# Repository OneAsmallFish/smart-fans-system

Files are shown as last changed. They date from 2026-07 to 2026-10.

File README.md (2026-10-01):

<div align="center">

# 🌀 Smart Fan Controller

**服务器智能风扇控制系统**

*ESP32-S3 powered server fan management — 8-channel PWM, multi-sensor, MQTT, Web dashboard, Home Assistant*










[🌐 Project Page](https://oneasmallfsh.github.io/smart-fans-system/) · [📖 Deploy Guide](docs/deploy.md) · [🔧 Hardware Guide](docs/hardware-assembly.md) · [📡 MQTT Protocol](docs/protocol.md)

</div>

---

## 目录 / Contents

- [功能特性](#-功能特性)
- [系统架构](#-系统架构)
- [快速开始](#-快速开始)
- [硬件规格](#-硬件规格)
- [软件组件](#-软件组件)
- [Web 控制台](#-web-控制台)
- [Home Assistant 集成](#-home-assistant-集成)
- [项目结构](#-项目结构)
- [开发指南](#-开发指南)
- [许可证](#-许可证)

---

## 🏗️ 系统架构

```
┌──────────────────────────────────── 服务器机柜 ─────────────────────────────────────┐
│                                                                                      │
│  ┌─────────────────────────────┐     USB-CDC      ┌──────────────────────────────┐  │
│  │     ESP32-S3-N16R8 (固件)    │ ◄──────────────► │   Go Agent (Linux 守护进程)   │  │
│  │                             │                  │                              │  │
│  │  8× 25kHz PWM 风扇控制       │      MQTT        │  · nvidia-smi  GPU 监控      │  │
│  │  8× PCNT Tach 转速反馈       │ ◄──────────────► │  · /proc/stat  CPU 利用率    │  │
│  │  BME280  温湿度气压           │                  │  · /proc/meminfo 内存        │  │
│  │  DS18B20 远程温度探头         │                  │  · systemd 服务自启动        │  │
│  │  12V/5V/3.3V 电源监控        │                  └──────────────────────────────┘  │
│  │  WS2812B RGB 状态 LED        │                                                    │
│  │  OTA 固件空中升级             │                                                    │
│  └─────────────────────────────┘                                                    │
│               │ SATA 15Pin (12V + 5V)                                               │
└───────────────┼─────────────────────────────────────────────────────────────────────┘
                │ WiFi  ───  MQTT Broker (Mosquitto)
                │                    │
          ┌─────┴──────┐   ┌─────────┼──────────┐   ┌─────────────────────┐
          │  Web APP   │   │  Home   │          │   │   其他 MQTT 客户端   │
          │ React+Node │   │Assistant│ packages │   │  (Node-RED / 脚本)  │
          └─────┬──────┘   └─────────┴──────────┘   └─────────────────────┘
                │ WebSocket 实时推送
                └── Dashboard · 风扇控制 · 告警配置 · 历史图表 · 设备管理
```

## ✨ 功能特性

| 特性 | 说明 |
|---|---|
| 🌡️ **多传感器温度** | BME280 板载（温湿度气压）+ DS18B20 远程探头 + ESP32 内部温度 + GPU/CPU（Go Agent） |
| 🌀 **8路独立风扇** | 25 kHz PWM 精准调速 + PCNT 转速反馈（RPM），停转检测 |
| 📈 **双模控制曲线** | 固定查表（LUT）线性插值 + PID 自适应，每路独立配置 |
| ⚡ **电源监控** | 12V / 5V / 3.3V 实时采样，欠压/过压告警，断电保护电容 |
| 🔔 **智能告警** | 4类规则（温度/停转/电压/WiFi），三级状态机，2分钟去重，LED+MQTT通知 |
| 🌐 **Web 控制台** | React 仪表盘，实时 WebSocket 推送，风扇曲线编辑器，历史趋势图 |
| 🏠 **Home Assistant** | ha/ 手动 packages 集成（17个传感器 + 8路风扇控制 + 5个告警/在线传感器；Discovery 为规划项） |
| 🔄 **OTA 固件更新** | MQTT / USB-CDC 双触发，3阶段回滚保护（启动/网络/MQTT确认） |
| 🖥️ **Go Linux Agent** | nvidia-smi GPU 监控 + /proc 系统采集，单二进制，systemd 服务 |
| 🔌 **SATA 直取供电** | 服务器 SATA 电源口供电，5V→AMS1117-3.3V LDO，12V 直供风扇 |

---

## 🚀 快速开始

### 前置要求

```bash
# ESP-IDF v5.3+（固件编译）
. $IDF_PATH/export.sh

# Go 1.22+（Agent）
go version  # go version go1.22 linux/amd64

# Node.js 20+（Web 控制台）
node --version  # v20.x.x

# Mosquitto（MQTT Broker）
mosquitto -v  # 2.x.x
```

### 1 — 烧录固件

```bash
cd firmware
idf.py set-target esp32s3
idf.py build
idf.py -p /dev/ttyACM0 flash monitor
# 首次上电后长按配网键(3s)，连接 FanCtrl-XXXXXX 热点配网
```

### 2 — 部署 Go Agent（Linux 服务器）

```bash
cd agent
make build
sudo bash install.sh    # 安装到 /usr/local/bin + systemd 服务
# 编辑配置
sudo nano /etc/smart-fan-agent/config.yaml  # 填入 MQTT broker 地址和串口路径
sudo systemctl start smart-fan-agent
```

### 3 — 启动 Web 控制台

```bash
# 后端
cd web/backend && npm install && npm start   # http://localhost:3001
# 前端（开发模式）
cd web/frontend && npm install && npm run dev  # http://localhost:5173
```

### 4 — Home Assistant 集成（手动 packages）

```bash
# 1. 获取 device_id（订阅 status topic 或看固件启动日志）
mosquitto_sub -t 'fan-controller/+/status' -v
# 2. 复制 YAML 到 HA 并替换占位符（详见 ha/README.md）
cp -r ha/ /config/packages/fan-controller/
sed -i 's/__DEVICE_ID__/esp32-a1b2c3/g' /config/packages/fan-controller/*.yaml
# 3. configuration.yaml 启用 packages 后重启 HA
```

> 固件不实现 MQTT Discovery 自动发现（规划中）；必须替换 `__DEVICE_ID__` 占位符，
> 否则控制实体无法下发命令。

> 完整部署说明见 [docs/deploy.md](docs/deploy.md)

---

## 🔧 硬件规格

| 参数 | 规格 |
|---|---|
| **主控** | ESP32-S3-N16R8（16MB Flash + 8MB Octal PSRAM） |
| **供电** | SATA 15Pin（12V + 5V），板载 AMS1117-3.3 LDO |
| **风扇** | 8路 4Pin 25kHz PWM（Intel 规范），SATA 12V 直供 |
| **传感器** | BME280（I2C, GPIO17/18）+ DS18B20（1-Wire, GPIO16, 最多4个，不支持寄生供电） |
| **电平转换** | 74AHCT125（ESP32 3.3V → 5V PWM 信号），Tach 5V→3.3V 分压 |
| **LED** | WS2812B-2020 RGB（3.3V 供电，GPIO45 RMT，5种状态模式） |
| **按键** | WiFi 配网（GPIO47，长按3s/10s；AP 配网需输入串口日志打印的4位确认码），复位（EN 引脚） |
| **通信** | WiFi 802.11b/g/n + USB-CDC 原生（无需转串口芯片） |
| **保护** | PTC 保险丝 + 肖特基防反接 + TVS ESD + 断电保护电容 |
| **PCB** | 99mm × 99mm，4 层 FR4（L2 完整 GND），嘉立创免费打样档 |

### 🔑 关键硬件设计决策

- **12V ADC 分压**：`100kΩ + 20kΩ`（ADC 输入≤2.0V，防止超出 ESP32-S3 ADC 上限3.1V）
- **WS2812B 3.3V 供电**：3.3V 时 VIH_min=2.31V < ESP32 VOH=3.0V ✅；若5V供电则逻辑电平不足
- **不使用 SATA 3.3V 引脚**：改用 5V→LDO 方案，电流裕量更大且无 PWDIS 兼容性问题

---

## 💻 软件组件

```
smart-fans-system/
├── firmware/                  # ESP32-S3 固件（ESP-IDF v5.3, C语言）
│   ├── components/            # 13个独立驱动组件
│   │   ├── power_monitor/     # ADC1 电源监控（仅ADC1，避开ADC2/WiFi冲突）
│   │   ├── fan_pwm/           # LEDC 25kHz PWM（LEDC_LOW_SPEED_MODE）
│   │   ├── fan_tach/          # PCNT 转速计（RPM = pulses×60÷2）
│   │   ├── bme280/            # I2C BME280（Bosch 补偿算法，int64_t 防溢出）
│   │   ├── ds18b20/           # OneWire DS18B20（CRC8 + ROM 搜索）
│   │   ├── status_led/        # WS2812B RMT（5种模式：正常/警告/错误/配网/OTA）
│   │   ├── wifi_manager/      # WiFi STA+AP + Captive Portal + 指数退避重连
│   │   ├── mqtt_client/       # MQTT（LWT 遗嘱 + 50条 Flash 离线队列）
│   │   ├── usb_console/       # USB-CDC 串口控制台（7命令：help/status/reboot/ota/fan/wifi/mqtt）
│   │   ├── flash_storage/     # NVS配置 + Wear Levelling 循环日志
│   │   ├── fan_curve/         # LUT插值 + PID Anti-windup + 紧急模式(>80°C)
│   │   ├── alert_manager/     # 4类告警规则 + NORMAL/WARNING/CRITICAL状态机
│   │   └── ota_handler/       # esp_https_ota + 3阶段回滚保护
│   └── test/                  # 13个 Unity 测试文件（未接入 idf.py 构建，见下方说明）
│
├── agent/                     # Go Linux Agent
│   ├── internal/monitor/      # GPU（nvidia-smi）+ 系统（/proc）采集器
│   ├── internal/mqtt/         # MQTT 发布/订阅（paho.mqtt.golang）
│   └── internal/usb/          # USB-CDC 串口双向中继
│
├── web/                       # Web 控制台
│   ├── backend/               # Express + MQTT + WebSocket（2秒推送）
│   │   └── src/routes/        # 8+端点 + Zod 参数校验
│   └── frontend/              # React + TypeScript + Vite + Recharts
│       ├── pages/             # Dashboard · Fans · Alerts · History · Devices
│       └── components/        # TemperatureGauge · FanCard · VoltageBar · CurveEditor
│
├── ha/                        # Home Assistant 手动 packages 配置（__DEVICE_ID__ 占位）
├── hardware/                  # 硬件设计文件（嘉立创 EDA 工程 + BOM + Gerber；旧 KiCad 工程归档 legacy/）
├── test/                      # 端到端集成测试 + 冒烟测试脚本
│   └── simulator/             # 无硬件协议模拟器（esp32-sim0001，Web/HA 全链路联调）
└── docs/                      # 部署指南 + 硬件组装指南 + MQTT协议规范
```

---

## 📊 Web 控制台

浏览器访问 `http://server-ip:5173`（开发）或 nginx 反代后访问。

- **Dashboard** — 实时温度仪表（RadialBarChart）、风扇 RPM/占空比图表、电压进度条、告警横幅
- **Fans** — 8路独立调速滑块（AUTO/MANUAL 切换）、LUT 曲线可视化编辑、PID 参数面板
- **Alerts** — 4类告警规则开关+阈值配置、告警历史时间线（最近100条）
- **History** — 温度/转速趋势图（Recharts LineChart）、时间范围选择（1h/6h/24h/7d）、CSV 导出
- **Devices** — 在线状态监控、OTA 固件更新触发、设备重启（二次确认）

---

## 🏠 Home Assistant 集成（手动 packages）

通过 `ha/` 目录的 YAML packages 手动集成（MQTT Discovery 自动发现为规划项，当前不实现）：

| 实体类型 | 数量 | 说明 |
|---|:---:|---|
| 传感器（Sensor） | 17 | BME280×3 + DS18B20×2（按 address 匹配）+ MCU温度 + 电压×3 + 风扇RPM×8 |
| 风扇（Fan） | 8 | 0~100% 调速控制（command_topic 指令） |
| 二进制传感器 | 5 | 温度告警 / 停转告警 / 电压异常 / WiFi告警 / 设备在线（per-type retained 状态 topic） |

安装步骤与 `__DEVICE_ID__` 占位符替换方法见 [ha/README.md](ha/README.md)。
全部实体带 availability 联动（设备 LWT 下线即不可用）。

---

## 🛠️ 开发指南

### ESP-IDF 已知陷阱（来自实战踩坑）

| # | 陷阱 | 正确做法 |
|---|---|---|
| 1 | `esp_timer_get_time()` 用 `uint32_t` 接收 | **必须 `int64_t`**，72分钟后溢出 |
| 2 | SNTP 在 `WIFI_EVENT_STA_CONNECTED` 启动 | 必须在 `IP_EVENT_STA_GOT_IP` 启动 |
| 3 | `esp_mqtt_client_start()` 在WiFi事件处理器中 | 用 FreeRTOS Timer 延迟调用 |
| 4 | `sscanf` 解析 JSON | 始终用 `cJSON` 库 |
| 5 | `vTaskDelay` 在事件处理器内 | 改用 `esp_rom_delay_us()` |
| 6 | LEDC 硬件渐变 + WiFi 并发 | 手动步进（独立任务），不用 `ledc_set_fade_with_time()` |

### 运行单元测试 / 构建

```bash
# 固件（⚠️ firmware/test/ 的 13 个 Unity 测试文件未接入 idf.py 构建——DESCOPE，
# 见 docs/changelog-modules-v1.2.md DOC-06；当前固件验证以 build + 冒烟为准）
cd firmware && idf.py build

# agent（Linux 交叉编译）
cd agent && GOOS=linux go build ./... && go vet ./...

# web（真实构建命令；无 jest 测试套件，README 此前的 `cd web && npm test` 不存在）
cd web/backend  && npm ci && npm run build   # 产出 dist/server.js
cd web/frontend && npm ci && npm run build   # 产出 dist/index.html
```

### 运行冒烟测试

```bash
./test/smoke_test.sh <mqtt_host> <api_host>
# 预期输出: PASS: 25  FAIL: 0（含 TST-04 协议命令用例；其中 8 项为静态断言）
```

### 无硬件联调（协议模拟器）

```bash
cd test/simulator && npm ci
node simulator.js --broker mqtt://<broker_host>:1883
# 模拟设备 esp32-sim0001 上线并周期上报，可在 Web 控制台查看/控制
# 详见 test/simulator/README.md；契约自检: node selftest.js --broker mqtt://<broker>:1883
```

---

## 📄 许可证

[MIT License](LICENSE) — 自由使用、修改和分发。

本项目为个人 DIY 项目，不提供任何形式的商业支持或质量保证。

---

<div align="center">

Made with ❤️ for homelab enthusiasts · [⭐ Star on GitHub](https://github.com/OneAsmallFish/smart-fans-system)

</div>

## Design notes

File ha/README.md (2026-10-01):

# ha/README.md — Home Assistant 集成步骤（手动 packages 方案）

# Smart Fan Controller — Home Assistant 集成指南

## 前提条件

- Home Assistant 2024.1+
- Mosquitto broker 插件已安装并运行
- Smart Fan Controller 固件已烧录并已连接 WiFi

---

## 集成方法：手动 packages（ha/ 目录）

> **说明**：固件当前**不实现** MQTT Discovery 自动发现（规划中）。
> 集成方式为手动 packages —— 将 `ha/` 目录的 YAML 放入 HA 配置。

### 步骤

1. **获取 device_id**（二选一）：
   - 订阅设备状态 topic，等一条 retained 消息：
     ```bash
     mosquitto_sub -t 'fan-controller/+/status' -v   # 输出里的 esp32-XXXXXX 即 device_id
     ```
   - 或查看固件启动日志（USB-CDC 串口）：`Device ID: esp32-XXXXXX`

2. **获取 DS18B20 探头地址**（用于 sensors.yaml 的两个探头实体）：
   ```bash
   mosquitto_sub -t 'fan-controller/<device_id>/sensor/ds18b20' -v
   # payload 中 sensors[].address 形如 "28-a1b2c3d4e5f6"
   ```

3. **替换占位符并部署**（在仓库根执行）：
   ```bash
   mkdir -p /config/packages/fan-controller
   sed -e 's/__DEVICE_ID__/<你的device_id>/g' \
       -e 's/__DS_ADDR_0__/<探头0地址>/g' \
       -e 's/__DS_ADDR_1__/<探头1地址>/g' \
       ha/fans.yaml ha/alerts.yaml ha/sensors.yaml \
       > /dev/null   # 先 dry-run 确认，或直接逐文件输出：
   # cp 到 HA 配置目录：
   cp ha/fans.yaml ha/alerts.yaml ha/sensors.yaml /config/packages/fan-controller/
   # 然后在 HA 宿主机上执行 sed 批量替换：
   sed -i -e 's/__DEVICE_ID__/esp32-a1b2c3/g' \
          -e 's/__DS_ADDR_0__/28-xxxxxxxxxxxx/g' \
          -e 's/__DS_ADDR_1__/28-yyyyyyyyyyyy/g' \
          /config/packages/fan-controller/*.yaml
   ```

4. **在 configuration.yaml 中启用 packages**：
   ```yaml
   homeassistant:
     packages:
       fan_controller: !include_dir_named packages/fan-controller
   ```

5. **重启 Home Assistant**，实体生效：
   - 温度/湿度/气压（BME280）×3 + DS18B20 探头 ×2 + MCU 温度 ×1
   - 12V / 5V / 3.3V 电压监控 ×3
   - 风扇 0-7 转速（RPM）×8
   - 风扇 0-7 转速控制（0-100%）×8
   - 告警二进制传感器 ×4（温度/停转/电压/WiFi）+ 设备在线 ×1

> ⚠️ **必须替换 `__DEVICE_ID__`**：固件按具体 device_id 订阅命令（不做通配订阅），
> 不替换的 HA 配置将无法控制设备。旧的隐性占位 device_id 已废弃。

---

## 告警自动化示例

```yaml
# 温度过高时发送通知
automation:
  - alias: "Fan Controller High Temperature"
    trigger:
      - platform: state
        entity_id: binary_sensor.fan_controller_temperature_alert
        to: "on"
    action:
      - service: notify.mobile_app
        data:
          message: "服务器温度过高！检查风扇控制器。"
```

---

## MQTT Discovery（规划中）

自动发现为规划功能（protocol.md §8）；当前方案为上述手动 packages。

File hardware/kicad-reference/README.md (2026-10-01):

# hardware/kicad-reference — KiCad 参考稿（非权威）

> **定位（决策 D6）**：嘉立创 EDA 工程（`hardware/lceda/`，用户手绘）是**唯一硬件真源**。
> 本目录的 KiCad 工程是由整改 agent 生成的**对比参照稿**——用于和您在嘉立创中绘制的
> 版本对照电路结构、网络命名与引脚分配。**禁止用于配单、打样或作为设计依据。**

## 文件清单

| 文件 | 说明 |
|---|---|
| `smart-fan-controller-v1.2.kicad_sch` | v1.2 完整原理图（KiCad 10，A2 单页，全局标签建网） |
| `smart-fan-controller-v1.2.kicad_pro` | 配套工程文件（KiCad GUI 直接打开用） |
| `smart-fan-controller-v1.2-ref.pdf` | 原理图 PDF 导出（无需 KiCad 即可对照） |
| `nl.net` | KiCad 网表导出（网络连通性证据） |
| `generate_sch.py` | 生成器脚本（可复现：`python generate_sch.py`，需本机 KiCad 10 标准库） |

## 设计依据

与嘉立创版完全一致，均来自 `hardware/docs/remediation-plan-v1.2.md`（v1.2.2）§1~§3：

- 8 路风扇：GPIO5~12 → 74AHCT125 ×2（OE 全接地）→ FAN1~8_PWM_OUT；每路 PWM 线 10kΩ 下拉（H-17）
- 8 路 Tach：GPIO13/14/15/21/38/39/40/41，每路 10k 上拉(+5V)+10k 串联+10k 下拉+1nF（3R+1C）
- ADC：GPIO1(÷6, 100k/20k)、GPIO2(÷5.7, 47k/10k)、GPIO4(÷5.7, 47k/10k)
- 电源：SATA → F1(≥3A)+D1 → +12V；SATA 5V→F2+D2 与 USB VBUS→D3 二极管或 → +5V → AMS1117-3.3
- USB：USB_C_Receptacle + USBLC6-2P6（VCC=**+5V**，H-08）+ CC 5.1k×2
- WS2812B-2020（GPIO45，串 33R）；BME280（SDO→GND=0x76，CSB→3V3）；DS18B20×2 端子（J11/J12）
- J13 屏幕排针（GPIO42/43/44+10k上拉/48 + I2C）；EN/BOOT 按键+上拉+去抖；WiFi 按键 GPIO47
- GPIO3/46 与 USB-C 未用脚（TX/RX/SBU）全部 no_connect；GPIO35/36/37 no_connect（N16R8 不可用）

## ERC 结果（KiCad 10.0.5 实测）

```
0 Errors / 11 Warnings
```

- 10 × `lib_symbol_mismatch`（74AHCT125）：生成器把 `extends 74LS125` 的继承符号展平嵌入，
  与库文件逐字节不同但引脚/电气完全一致——外观性差异，可忽略。
- 1 × `pin_to_pin`（U5/BME280 SDO ↔ GND）：**有意设计**（SDO 接地选 I2C 地址 0x76），非缺陷。

网表抽查（`nl.net`）：FAN1_PWM={U2.5,U3.2,R4.1}、FAN8_TACH={U2.34,R41.2,R42.1,C20.1}、
RESET={U2.3,R1.2,SW1.1,C6.1}、DS18B20_DQ={U2.9,R52.2,J11.2,J12.2} 等均与设计一一对应。

## 与嘉立创版对照时请以本表为准的差异说明

- 本稿为单页 A2、全局标签建网（无导线），元件摆放按功能分区，不代表 PCB 布局意图。
- 位号与 v1.2 规范一致：J1 SATA、J2 USB-C、J3~J10 风扇座、J11/J12 DS18B20、J13 屏幕、
  U3/U4 为两片 74AHCT125、U5 BME280、U6 USBLC6（注意：设计指南中 USBLC6 记作 U5，此稿为 U6）。
- 去耦电容数量为示意（ESP32 画了 4 只，BOM 要求 ≥8 分布 VDD）。
- 本稿无 PCB。布局/叠层请完全以嘉立创版与设计指南 v1.2 §PCB 约束为准。

## 复现方法

```bash
cd hardware/kicad-reference
python generate_sch.py    # 重新生成 .kicad_sch（覆盖）
# 验证（路径需绝对路径 + .kicad_sch 扩展名）：
"D:/Program Files/KiCad/10.0/bin/kicad-cli.exe" sch erc --output erc.rpt \
  "E:/My_Opjects/smart-fans-system/hardware/kicad-reference/smart-fan-controller-v1.2.kicad_sch"
```

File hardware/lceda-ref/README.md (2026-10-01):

# hardware/lceda-ref — 嘉立创 EDA 参考稿（非权威）

> **定位（决策 D6）**：您在嘉立创 EDA 中手绘的工程是**唯一硬件真源**。
> 本目录记录 agent 通过 EasyEDA Pro API 生成的**对比参照稿**及其脚本，
> 用于与您的手绘版对照电路结构与网络命名。**禁止用于配单/打样。**

## 参照稿位置（EasyEDA Pro 本地工程）

- 工程名：**SmartFan-v1.2-ref**（单机版本地工程）
- 路径：`C:\Users\OneAs\Documents\LCEDA-Pro\projects\SmartFan-v1.2-ref`
- 打开方式：嘉立创 EDA 专业版 → 工程树 → main/SmartFan-v1.2-ref → 双击 `1. P1`

## 完成状态

### ✅ 原理图（完整）
- A0 图页，**95 个元件**全部放置并设位号/名称，全部引脚按 v1.2 网络命名
  （`remediation-plan-v1.2.md` §1 权威表）挂网络标签/电源标志：
  - U1 AMS1117-3.3(C6186)、U2 ESP32-S3-WROOM-1-N16R8、U3/U4 SN74AHCT125D（各 5 子部件：
    4 门 + 电源单元，OE 全接 GND）、U5 BME280、U6 USBLC6-2SC6(C7519)
  - J1 SATA7+15、J2 TYPE-C-31-M-12、J3~J10 640454-4 风扇座、J11/J12 XH2.54-3P、J13 1x8 2.54 排母
  - 8 路 PWM（FAN1~8_PWM→缓冲→FAN1~8_PWM_OUT，每路 10k 下拉 R4~R11）
  - 8 路 Tach 网络（3R+1C ×8：R12~R42 + C13~C20）
  - ADC 分压三组（R44~R49）、I2C/OneWire 上拉（R50~R52）、EN/BOOT 电路（R1/R2/SW1/SW2/C6）
  - WiFi 按键（R54/SW3）、WS2812B-2020（R53 串阻）、USB CC 下拉（R55/R56）、VBUS 电容（C22/C23）
  - 电源区（F1 ≥3A PTC、F2 1A PTC、D1 SS34、D2/D3 B5819W 二极管或、AMS1117、输入电容组）
- 网络命名与 KiCad 参考稿（`hardware/kicad-reference/`）完全一致，可逐网对照。
- 已保存（无未保存标记）。

### ✅ DRC 修复完成（158 致命 → 9 致命 / 320 警告 / 0 错误）

**158→9 过程**（三轮修复）：
1. 根因 1（约 149 个致命）：API `createNetLabel()` 在引脚坐标处创建了图元但未与引脚
   电气连接（嘉立创引脚吸附需要网格对齐，API 坐标存在亚网格偏移）。修复：改用
   `sch_PrimitiveWire.create([px, py, px+dx, py+dy], net)` 从每个引脚画一段带网络名的
   短导线（305 根），导线强制按 net 参数赋网络 → 引脚通过导线接入网络。
2. 根因 2（约 9 个致命）：U3/U4 的 SN74AHCT125D 多子部件（5 部件共享位号）导致
   "位号重复" + "引脚与焊盘未对应"（每部件仅 3 脚 vs SO-14 焊盘 14 脚）。修复：
   删除 10 个多子部件实例，替换为 **74AHCT125D-Q100118**（单部件 14 脚符号，
   SO-14 同封装），2 片各 14 脚全部正确接线。
3. 根因 3：`pin.modify({noConnected: true})` 未生效（API 返回成功但 DRC 仍报悬空）。
   NC 引脚的悬空已从致命降为警告级别。

### 剩余 9 致命 + 320 警告（需在编辑器中目视处理）
- 9 致命 = 引脚悬空（net flag/label 图元与引脚的网格吸附偏差导致电气未连通）。
  修复方法：在编辑器中打开原理图，DRC 面板双击每条致命错误定位到引脚，
  将附近的网络标签拖到引脚端点（或删掉重放）。约 10 分钟手工操作。
- 320 警告 ≈ 300 条 NC 引脚悬空（`pin.modify({noConnected:true})` API 未生效）
  + 20 条供应商编号不匹配（API 命名与库标准差异，不影响功能）。
  NC 引脚悬空为警告级别，不影响 PCB 转换。

### 手工完成 PCB 的步骤
1. 打开工程，激活原理图页 → 编辑器中修复 9 条致命悬空（DRC 面板双击定位）。
2. 顶部菜单 **设计 → 更新/转换原理图到PCB**（或 Alt+I）→ 确认导入。
3. PCB 中：边框层画 99×99mm 板框 → 层管理加两个内层（L2 GND / L3 电源）。
4. 布局按 `hardware-design-guide-v1.2.md` §PCB 约束。
5. **手工布线**（勿用自动布线）。
6. 完成后归档到仓库 `hardware/lceda/`（D6 口径）。

## 脚本说明（本目录 scripts/）

| 文件 | 用途 |
|---|---|
| `lceda_exec.py` | 向 EasyEDA Pro 桥接服务（localhost:49620）发送 JS 并打印结果 |
| `search_all*.js` | 库搜索（器件名 → LCSC 编号/封装核对） |
| `probe_place.js` / `probe2.js` | 首批唯一类型元件放置 + 引脚结构/子部件探测 |
| `batch1_power.js` ~ `batch6_labels.js` | 分区批量放置 + 全部网络标签/电源标志 |
| `shift_y.js` / `revert_y.js` | （已回退的）整版平移试验 |

复现：EasyEDA Pro 打开工程 + 桥接服务运行（`node <skill>/scripts/bridge-server.mjs`）后，
`python lceda_exec.py batch1_power.js` 依序执行。

## 已知注意事项

- 参考稿中 USBLC6 位号为 **U6**（设计指南文本写 U5）；74AHCT125 为 U3/U4（与 KiCad 稿一致）。
- SATA 符号（sata7+15）引脚按"1-7 数据(NC)、8-10=3.3V(NC/PWDIS)、11-19=GND/5V、20-22=12V"
  惯例映射（嘉立创该符号引脚无命名，此为社区通用约定，画正式板时请核对实物引脚图）。
- 去耦电容数量为示意（ESP32 画 4 只，BOM 要求 ≥8）。
- 嘉立创库元件与 BOM v1.2 的 LCSC 编号对应关系已在脚本 search 步骤核实（C6186/C7519/C8678 等）。

---
生成日期：2026-09-06；生成方式：EasyEDA Pro API（run-api-gateway 扩展 + WebSocket 桥接）

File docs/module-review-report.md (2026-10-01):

# 模块审查报告（Module Review Report）

> 依据：`docs/module-review-plan.md` v1.0（2026-08-23）
> 审查日期：2026-08-24 · 审查 agent：ZCode（GLM-5.3）
> 硬件参照：`hardware/docs/remediation-plan-v1.2.md` §1 v1.2 引脚表（经核实 H-03 **尚未执行**，全文件 grep 证据见 §9.4-E）
> 规则遵守：R1 逐文件全文审查 ✓（覆盖矩阵 100%）｜R2 证据留痕 ✓｜R3 可执行验证真实执行 ✓（idf.py BLOCKED，其余已执行）｜R4 只报告不修复 ✓（本轮零代码提交）｜R5 逐行比对 ✓｜R6 数字矛盾全报 ✓｜R7 固定格式 ✓

---

## 执行摘要

全仓库 **6 个模块 90 个条目（88 个文件 + .omo/.sisyphus 两个目录级条目）全文审查完毕**。总体结论：**该项目当前处于"演示级脚手架"状态，六个模块中有四个无法通过各自的构建/运行验证**，且各模块之间存在系统性的协议偏差（协议真源 protocol.md 与各实现之间存在字段类型、topic 位置、数量口径三类漂移）。

| 模块 | 构建/运行验证结果 | Critical | Major |
|---|---|:---:|:-----:|
| A firmware | `idf.py` BLOCKED（无环境）；**静态判定 2 处编译错误** | 6 | 17 |
| B agent | `go build` **失败**（unused import + go.sum 缺失）；main.go 为空壳 | 2 | 3 |
| C web | backend `tsc` **无配置不成编译**；frontend build **失败**（缺 tsconfig/index.html/入口） | 2 | 5 |
| D ha | YAML 语法 ✓；2 个风扇实体 vs 文档 4 路、占位 device_id | 1 | 2 |
| E test | `bash -n` ✓；**首个 PASS 即自毁**（set -e + `((PASS++))`） | 1 | 1 |
| F docs/root | — | 0 | 4 |

最严重的十个问题（详见 §9.2）：
1. **MA-01/02** 固件静态可判定的编译错误（`ESP_ERROR_CHECK(void)`、main 组件依赖缺失）——固件从未成功编译过。
2. **MA-03** MQTT 订阅在客户端创建前调用且无重订阅 → **设备永远收不到任何命令**。
3. **MA-04** WiFi 连接回调把 FreeRTOS 定时器句柄当 broker_url 指针解引用 → 首次连上 WiFi 即未定义行为。
4. **MA-05** OTA 三阶段确认的第三阶段（`ota_handler_confirm_mqtt`）全仓库零调用 → 任何 OTA 成功后 5 分钟必回滚，OTA 功能性死亡。
5. **MA-06** 停转告警条件 `rpm > 0 && rpm < 200` → 完全堵转（0 RPM）反而不告警。
6. **MB-01/02** agent 编译失败（gpu.go unused import + go.sum 缺失）+ main.go 空壳（MQTT/采集/串口全部是 TODO 注释）。
7. **MC-01/02** web 前后端构建链断裂（无 tsconfig；前端无 index.html/main.tsx/vite.config）。
8. **MA-07** H-03 未执行且波及面比整改清单更大（PCNT 单元耗尽、分压比常数 ×2.0 vs 硬件 ÷5.7、五处硬编码"4"）。
9. **MD-01 + MA-35** ha fans.yaml 用 `esp32-placeholder` 占位 device_id 发命令；固件订阅 `+/command/#` 通配且不校验 device_id——两个错误"负负得正"地互相掩盖。
10. **协议 timestamp 全面错误**：固件所有上报的 `timestamp` 是开机秒数而非 Unix 秒（MA-12），直接导致 web History 页时间显示为 1970 年附近（MC-12）。

---

## 9.1 覆盖矩阵

行数 = `wc -l` 实测。状态定义：`全文已读` = 完整阅读并审查；`+已验证` = 另有针对该文件执行过的验证命令（grep/构建/解析，证据见 §9.4）。

### 模块 A：firmware（44 文件）

| 文件 | 行数 | 状态 | 备注 |
|---|-----:|---|---|
| firmware/CMakeLists.txt | 8 | 全文已读 | EXTRA_COMPONENT_DIRS 指向 components ✓ |
| firmware/partitions.csv | 8 | 全文已读 | 总占用 0x470000=4.4MB ≤16MB ✓；factory 1MB/ota 1.5MB 不对称（MF-09） |
| firmware/sdkconfig.defaults | 72 | 全文已读 | 缺 USB-CDC console 路由（MA-34）；coredump 分区未启用对应配置（MF-09） |
| firmware/main/main.c | 389 | 全文已读+已验证 | H-03 grep 验证（§9.4-E） |
| firmware/main/CMakeLists.txt | 17 | 全文已读 | **REQUIRES 缺全部 13 个自定义组件（MA-02）** |
| components/alert_manager/alert_manager.c | 152 | 全文已读 | 停转规则反转（MA-06） |
| components/alert_manager/alert_manager.h | 42 | 全文已读 | |
| components/alert_manager/CMakeLists.txt | 5 | 全文已读 | |
| components/bme280/bme280.c | 185 | 全文已读 | 引脚 17/18 与 v1.2 一致 ✓ |
| components/bme280/bme280.h | 18 | 全文已读 | |
| components/bme280/CMakeLists.txt | 5 | 全文已读 | |
| components/ds18b20/ds18b20.c | 236 | 全文已读 | GPIO16 ✓；bit-bang 而非注释声称的 RMT（MA-24） |
| components/ds18b20/ds18b20.h | 30 | 全文已读 | |
| components/ds18b20/CMakeLists.txt | 5 | 全文已读 | |
| components/fan_curve/fan_curve.c | 177 | 全文已读 | set_lut/set_pid/set_temp_source 零调用方（MA-20） |
| components/fan_curve/fan_curve.h | 42 | 全文已读 | 声称"NVS 保存"未实现（MA-20） |
| components/fan_curve/CMakeLists.txt | 5 | 全文已读 | |
| components/fan_pwm/fan_pwm.c | 96 | 全文已读+已验证 | H-03 grep；软启动任务竞态（MA-18） |
| components/fan_pwm/fan_pwm.h | 22 | 全文已读+已验证 | |
| components/fan_pwm/CMakeLists.txt | 5 | 全文已读 | |
| components/fan_tach/fan_tach.c | 94 | 全文已读+已验证 | H-03 grep；8 路时 pcnt_new_unit 耗尽（MA-07） |
| components/fan_tach/fan_tach.h | 21 | 全文已读+已验证 | |
| components/fan_tach/CMakeLists.txt | 5 | 全文已读 | |
| components/flash_storage/flash_storage.c | 147 | 全文已读 | WL 日志 ✓；storage_write_config 运行时零调用 |
| components/flash_storage/flash_storage.h | 38 | 全文已读 | fan_rpm[4] 硬编码（MA-07 连带） |
| components/flash_storage/CMakeLists.txt | 5 | 全文已读 | |
| components/mqtt_client/mqtt_client_wrapper.c | 279 | 全文已读 | 订阅丢失/erase_all/队列竞态（MA-03/16/17） |
| components/mqtt_client/mqtt_client_wrapper.h | 41 | 全文已读 | MQTT_TOPIC_PREFIX="fan-controller" ✓ |
| components/mqtt_client/CMakeLists.txt | 5 | 全文已读 | |
| components/ota_handler/ota_handler.c | 155 | 全文已读 | confirm_mqtt 零调用（MA-05）；无证书配置（MA-22） |
| components/ota_handler/ota_handler.h | 22 | 全文已读 | |
| components/ota_handler/CMakeLists.txt | 5 | 全文已读 | |
| components/power_monitor/power_monitor.c | 130 | 全文已读+已验证 | H-03 grep；分压比 ×2.0 vs 硬件 ÷5.7（MA-21） |
| components/power_monitor/power_monitor.h | 34 | 全文已读+已验证 | |
| components/power_monitor/CMakeLists.txt | 5 | 全文已读 | |
| components/status_led/status_led.c | 161 | 全文已读+已验证 | LED_GPIO=48 vs v1.2=45 |
| components/status_led/status_led.h | 29 | 全文已读+已验证 | **void 返回值 vs ESP_ERROR_CHECK（MA-01）** |
| components/status_led/CMakeLists.txt | 5 | 全文已读 | |
| components/usb_console/usb_console.c | 168 | 全文已读 | 实际命令集 help/reboot/status/ota |
| components/usb_console/usb_console.h | 19 | 全文已读 | |
| components/usb_console/CMakeLists.txt | 5 | 全文已读 | |
| components/wifi_manager/wifi_manager.c | 319 | 全文已读+已验证 | H-03 grep；BTN_GPIO=38 vs v1.2=47 |
| components/wifi_manager/wifi_manager.h | 35 | 全文已读 | |
| components/wifi_manager/CMakeLists.txt | 6 | 全文已读 | |

计划外发现（不在 §2.1 清单、未列入矩阵，仅登记）：`firmware/test/` 13 个 .c 文件（Unity 测试），**未被任何 CMakeLists 引用、从不参与编译**；README 称"12 个"且称可 `idf.py flash test` 运行（MF-05）。

### 模块 B：agent（12 文件）

| 文件 | 行数 | 状态 | 备注 |
|---|-----:|---|---|
| agent/go.mod | 17 | 全文已读+已验证 | go.sum 缺失（MB-01）；module path 占位符 `github.com/user/...` 本身不阻断构建 |
| agent/Makefile | 28 | 全文已读 | install 目标引用不存在的 smart-fan-agent.service（MB-03） |
| agent/agent.service | 24 | 全文已读 | User=nobody 无串口权限（MB-05） |
| agent/install.sh | 49 | 全文已读 | set -euo pipefail ✓；service 文件名断链（MB-03） |
| agent/config.yaml | 15 | 全文已读 | 字段与 config.go 一一对应 ✓ |
| agent/cmd/agent/main.go | 40 | 全文已读 | **空壳：MQTT/采集/串口全部 TODO 注释（MB-02）** |
| agent/internal/config/config.go | 48 | 全文已读+已验证 | 无默认值/校验；port 字段死配置（MB-06） |
| agent/internal/monitor/collector.go | 25 | 全文已读+已验证 | |
| agent/internal/monitor/gpu.go | 82 | 全文已读+已验证 | **`"bytes"` unused（全平台编译错误）**（MB-01） |
| agent/internal/monitor/system.go | 179 | 全文已读+已验证 | Statfs 为 Linux-only（目标平台 OK，Windows 交叉验证受阻） |
| agent/internal/mqtt/client.go | 96 | 全文已读+已验证 | 订阅 command/# 偏离协议 §11（MB-04） |
| agent/internal/usb/relay.go | 79 | 全文已读 | Open() 无限阻塞重试（MB-08） |

### 模块 C：web（20 文件）

| 文件 | 行数 | 状态 | 备注 |
|---|-----:|---|---|
| web/backend/package.json | 26 | 全文已读+已验证 | build:"tsc" 无 tsconfig 可依（MC-02） |
| web/backend/src/server.ts | 39 | 全文已读+已验证 | 显式 tsc 通过 ✓ |
| web/backend/src/mqtt.ts | 101 | 全文已读+已验证 | fans 硬编码 4（MC-03）；缺 ota/status 订阅（MC-04） |
| web/backend/src/routes/devices.ts | 104 | 全文已读+已验证 | curve PID 嵌套结构偏离协议（MC-06） |
| web/backend/src/types.ts | 50 | 全文已读+已验证 | alert_type:number 跟随固件偏离协议 |
| web/frontend/package.json | 24 | 全文已读+已验证 | build:"tsc && vite build" 双断点（MC-01） |
| web/frontend/src/App.tsx | 34 | 全文已读+已验证 | |
| web/frontend/src/components/AlertRuleEditor.tsx | 91 | 全文已读 | 零引用死代码（MC-09） |
| web/frontend/src/components/CurveEditor.tsx | 138 | 全文已读 | 零引用死代码；无点数/占空比校验（MC-10） |
| web/frontend/src/components/DeviceCard.tsx | 107 | 全文已读 | 零引用死代码 |
| web/frontend/src/components/FanCard.tsx | 85 | 全文已读 | 零引用死代码 |
| web/frontend/src/components/OTAProgress.tsx | 87 | 全文已读 | 零引用死代码；无真实进度源 |
| web/frontend/src/components/TemperatureGauge.tsx | 32 | 全文已读 | 零引用死代码 |
| web/frontend/src/components/VoltageBar.tsx | 38 | 全文已读 | 零引用死代码；阈值与固件一致 ✓ |
| web/frontend/src/hooks/useWebSocket.ts | 56 | 全文已读+已验证 | 消息形状与 backend 逐字段一致 ✓ |
| web/frontend/src/pages/Alerts.tsx | 108 | 全文已读+已验证 | alert_type 误作 severity（MC-11） |
| web/frontend/src/pages/Dashboard.tsx | 132 | 全文已读+已验证 | 电压阈值与固件常数一致 ✓ |
| web/frontend/src/pages/Devices.tsx | 109 | 全文已读+已验证 | |
| web/frontend/src/pages/Fans.tsx | 200 | 全文已读+已验证 | 页头注释"4路"（表2）；滑块 stale state（MC-13） |
| web/frontend/src/pages/History.tsx | 105 | 全文已读+已验证 | 仅 fan0/fan1；时间显示受 MA-12 波及（MC-12） |

计划外发现：frontend 缺 `index.html`、`src/main.tsx`、`vite.config.ts`（vite 运行三要素全缺）；backend/frontend 均无 `tsconfig.json`。

### 模块 D：ha（4 文件）

| 文件 | 行数 | 状态 | 备注 |
|---|-----:|---|---|
| ha/README.md | 85 | 全文已读 | "自动发现无需配置"与固件无 discovery 代码矛盾（MA-23） |
| ha/fans.yaml | 37 | 全文已读+已验证 | YAML 解析 ✓；**仅 2 个风扇实体 + esp32-placeholder**（MD-01/02） |
| ha/sensors.yaml | 122 | 全文已读+已验证 | YAML ✓；10 实体（3v3 缺、DS 第二探头缺） |
| ha/alerts.yaml | 46 | 全文已读+已验证 | 模板逐消息翻转（MD-03） |

### 模块 E：test（2 文件）

| 文件 | 行数 | 状态 | 备注 |
|---|-----:|---|---|
| test/smoke_test.sh | 162 | 全文已读+已验证 | bash -n ✓；`((PASS++))` 自毁（ME-01） |
| test/e2e/integration_test.sh | 87 | 全文已读+已验证 | bash -n ✓；同病 + T4 无验证（ME-01/02） |

### 模块 F：docs 与仓库根（8 项）

| 文件 | 行数 | 状态 | 备注 |
|---|-----:|---|---|
| README.md | 277 | 全文已读 | 4 路/80×60 双层/HA"自动发现"等旧口径（MF-01~04） |
| docs/protocol.md | 497 | 全文已读 | 协议真源，作为 §9.3 各表左列 |
| docs/deploy.md | 255 | 全文已读 | 记载不存在的串口命令 fan/wifi（MF-06） |
| docs/hardware-assembly.md | 176 | 全文已读 | v1.1 口径；验收示例用不存在的 fan 命令（MF-07） |
| LICENSE | 21 | 全文已读 | MIT ✓ 与 README 徽章一致 |
| .gitignore | 60 | 全文已读 | 未忽略 `*.v7backup`（H-15 未落地）；.omo/.sisyphus 未忽略 |
| docs/index.html | 387 | 全文已读 | 计划外文件；80×60/4 路旧口径（MF-03） |
| .omo/ 与 .sisyphus/ | 163K×2 | 结构盘点 | `diff -rq` 字节级完全相同；旧 AI 执行计划+任务证据；双双被 git 跟踪（MF-08） |

**覆盖声明：§2~§7 文件清单 100% 覆盖，矩阵无空行。**

---

## 9.2 发现清单

格式：`编号 | 严重度 | 文件:行 | 证据摘录(≤3行) | 影响 | 建议修法`

### 模块 A：firmware

| 编号 | 严重度 | 文件:行 | 证据摘录 | 影响 | 建议修法 |
|---|:---:|---|---|---|---|
| MA-01 | **Critical** | firmware/main/main.c:371 + components/status_led/status_led.h:20 | `ESP_ERROR_CHECK(status_led_init());` / `void status_led_init(void);` | ESP_ERROR_CHECK 需要 esp_err_t 返回值，void 函数套入为**编译错误**——固件无法编译 | status_led_init 改为返回 esp_err_t |
| MA-02 | **Critical** | firmware/main/CMakeLists.txt:4-16 | `REQUIRES nvs_flash esp_wifi ... cJSON`（无任何自定义组件） | main.c include 的 13 个组件头文件路径不通，**编译错误** | REQUIRES 补 fan_pwm/fan_tach/fan_curve/alert_manager/bme280/ds18b20/power_monitor/status_led/wifi_manager/mqtt_client/usb_console/flash_storage/ota_handler |
| MA-03 | **Critical** | components/mqtt_client/mqtt_client_wrapper.c:262-264 + main.c:354 | `if (s_client && s_connected) { esp_mqtt_client_subscribe(...)` ; 调用点在 `mqtt_client_init()` 之后、`mqtt_client_connect()` 之前 | 订阅时客户端未创建，被静默跳过；MQTT_EVENT_CONNECTED 中亦无重订阅 → **设备永远收不到任何下行命令**（fan/ota/reboot 全部失效） | 在 MQTT_EVENT_CONNECTED 中订阅，或 mqtt_subscribe 缓存 topic 待连接后补订 |
| MA-04 | **Critical** | main.c:78-83 | `xTimerCreate("mqtt_st", ..., (void(*)(TimerHandle_t))mqtt_client_connect)` | 定时器回调把 TimerHandle_t 当 `broker_url` 传入；mqtt_client_connect 判空后跳过 NVS 分支，把句柄指针当 URI 字符串使用 → **首次 WiFi 连接触发未定义行为/崩溃**。注释"Pass NULL"与实际传参不符 | 改用带 user_data 的 timer 或独立标志，真正传 NULL |
| MA-05 | **Critical** | components/ota_handler/ota_handler.c:148-155 | `void ota_handler_confirm_mqtt(void)` — 全仓库 grep 零调用（§9.4-F） | OTA 三阶段确认第三阶段永不到达 → 任何成功 OTA 在 5 分钟看门狗到点后 `mark_app_invalid_rollback_and_reboot()` → **OTA 无限回滚循环** | 在 MQTT_EVENT_CONNECTED（或首次成功 publish）调用 confirm_mqtt |
| MA-06 | **Critical** | components/alert_manager/alert_manager.c:114 | `if (s_fan_rpm[i] > 0 && s_fan_rpm[i] < STALL_RPM)` | 卡死风扇完全停转（RPM=0）**不触发告警**；仅 1-199 RPM 报。fan_tach 的 3 秒停转回调送入 rpm=0 后被此条件丢弃 | 条件改为结合占空比判断：`duty>5 && rpm<STALL_RPM`（0% 占空比合法停转除外），需把 duty 传入 alert_manager |
| MA-07 | **Major** | components/fan_pwm/fan_pwm.h:9 等（证据 §9.4-E） | `#define FAN_PWM_COUNT 4` / `FAN_GPIO={4,5,6,7}` / `TACH_GPIO={8,9,10,11}` / `LED_GPIO 48` / `BTN_GPIO 38` / `CH_12V ADC_CHANNEL_2(GPIO3)` | **H-03 未执行**：全部引脚与 v1.2 权威表冲突（逐行见表6）。连带：TACH GPIO8-11 在 v1.2 是 FAN4-7_PWM（PWM/Tach 直接冲突）；GPIO3 是 strapping 禁用脚；8 路化时 `pcnt_new_unit`×8 会耗尽 S3 的 4 个 PCNT 单元（fan_tach.c:59 现按 unit=i 分配）；`VOLTAGE_DIVIDER_5V/3V3=2.0`（power_monitor.h:14-15）与 v1.2 硬件 47k/10k=÷5.7 不符（**此点 H-03 清单未覆盖**）；fan_curve.h:10 `FAN_CURVE_FANS 4`、flash_storage.h:17 `fan_rpm[4]`、main.c:280,301 与 alert_manager.c:35,87,113 的硬编码 4 都需联动 | 执行整改清单 H-03 并补充：分压比常数 ÷5.7、PCNT 改 `unit=i/2, channel=i%2`、五处硬编码 4 改宏 |
| MA-08 | **Major** | components/fan_pwm/fan_pwm.c:83-88 | `softstart_args_t *a = malloc(...); xTaskCreate(softstart_task, ...)` | 每次 set_duty 都派生新任务；fan_control_task 每秒调用 → 同一风扇多个软启动任务并发读写 `s_duty_pct[]` 与 LEDC 寄存器（竞态+任务churn） | 改为常驻控制器任务+目标值队列，或加互斥并在 set_duty 前终止旧任务 |
| MA-09 | **Major** | main.c:158-175 | `if (strstr(topic_str, "/command/fan")) {...} else if ("/command/ota") {...} else if ("/command/reboot")` | **command/curve、command/reset、config/# 全部无处理器**：协议 §4.2/§4.4/§6 的功能在固件端为零；web 的曲线编辑器、告警规则页对设备是空操作（且 handler 不校验 fan_index 越界/百分比值——靠下层 clamp 兜底） | 补三类 handler；fan_index 越界直接丢弃 |
| MA-10 | **Major** | main.c:107-110 | `cJSON_AddNumberToObject(root, "alert_type", ev->type);`（无 severity/sensor 字段） | 协议 §5 要求 alert_type 为字符串（"temperature_high"）+severity+sensor；固件发数字且缺两字段 → web/HA 被迫跟随错误口径（MC-09/MD-03 的根因） | 建立 type 枚举→字符串映射表并补 severity/sensor 字段 |
| MA-11 | **Major** | components/mqtt_client/mqtt_client_wrapper.c:219,137-145 | LWT: `"{\"status\":\"offline\"}"` ; online: 仅 status+device_id | 与协议 §1.1/§1.2 逐字段比对：LWT 缺 timestamp/device_id；online 缺 timestamp/firmware_version/ip_address/uptime_seconds → web 端 firmware/ip 字段永远 undefined | 按 §1.1 补全字段 |
| MA-12 | **Major** | main.c:49 等（全部 AddNumber timestamp 处） | `cJSON_AddNumberToObject(root,"timestamp",(int)(esp_timer_get_time()/1000000));` | **timestamp 语义错误**：协议规定 Unix 秒，固件发开机秒数。SNTP 已启动（wifi_manager.c:165-168）但时间从未被使用 → web History 时间轴显示 1970+uptime（MC-10） | 改用 `time(NULL)`，无网络时回退 uptime 并在 payload 标注 |
| MA-13 | **Major** | components/mqtt_client/mqtt_client_wrapper.c:116 + 273-275 | `nvs_erase_all(nvs);`（flush 队列时）/ `NVS_KEY_BROKER "broker_url"` 存于同一 NS "fan_mqtt" | 离线队列 flush 会**把 broker_url 一并删除** → 重启后无法重连 MQTT（USB 侧也没有配置 broker 的命令可补救） | 队列改用独立子 key 前缀或独立 namespace；逐 key erase |
| MA-14 | **Major** | mqtt_client_wrapper.c:62-95,180 | `offline_queue_push` 每次 push 全队列 50 条 blob 搬移；`s_queue_mutex` 创建后从未使用 | 断线期间 sensor/fan 每秒 ~8 条消息入队：NVS 写放大（满队后每条消息重写 50 blob）加速 flash 磨损；多任务并发调用 mqtt_publish 无锁竞态损坏队列 | 降频入队（协议 §10 的 30s 口径）+环形 key 复用+启用已创建的互斥锁 |
| MA-15 | **Major** | mqtt_client_wrapper.c:97-119 + 协议 §10 | flush 直接按原 topic 重发 | 协议 §10 要求 `/buffered` 后缀+`buffered:true` 标记；两端都未实现，web 的 `sensor/+` 订阅也匹配不到 5 级 topic | 固件加后缀+标记，backend 订阅改 `sensor/#` |
| MA-16 | **Major** | main.c:43-62 | payload 无 `mode` 字段（协议 §3.1 要求 auto/manual） | 前端 FanState.mode 永远停在默认 'auto'，手动模式状态不回显 | publish_fan_state 补 mode（从 fan_curve 状态读） |
| MA-17 | **Major** | components/ota_handler/ota_handler.c:52-58 | `.http_config = &(esp_http_client_config_t){ .url, .timeout_ms, .keep_alive_enable }`（无 cert_pem/crt_bundle_attach） | ESP-IDF 默认拒绝无凭据的 TLS 连接 → HTTPS OTA 大概率在连接阶段失败；注释声称"TLS 证书验证已启用"名不符实 | http_config 加 `.crt_bundle_attach = esp_crt_bundle_attach` 并启用证书 bundle |
| MA-18 | **Major** | main.c:347-368 | `ESP_ERROR_CHECK(wifi_manager_init(...)); ESP_ERROR_CHECK(wifi_manager_start());` 在风扇初始化（step 6）之前 | 任一步失败即 abort/重启循环 → **风扇控制永远不初始化**；对"风扇安全先于联网"的原则反向依赖（plan §2.3 main.c 检查点） | 风扇/PWM/曲线初始化提前到 WiFi 之前；WiFi 失败降级为本地控制 |
| MA-19 | **Major** | components/fan_pwm/fan_pwm.c:62-73 + remediation §3 | LEDC 配置前 GPIO4-7 悬空；v1.2 硬件 74AHCT125 OE 恒使能且无输入下拉 | 上电窗口期缓冲输出不定 → **风扇可能满转/乱转数百毫秒**（软件无早初始化、硬件无上拉/下拉，两头都没处理） | 固件在 app_main 最早处先配 LEDC duty=0；硬件侧 PWM 线加下拉（建议 10kΩ，列入硬件整改后续） |
| MA-20 | **Major** | components/fan_curve/fan_curve.h:32-33 + fan_curve.c 全文 | `/** 设置 LUT 曲线点（保存到 NVS）*/` — 实现中无任何 NVS 调用；`fan_curve_set_lut/set_pid/set_temp_source` 零调用方（§9.4-F grep） | 曲线配置掉电即失；协议 §4.2 的配置通道两端都断 | 实现 NVS 持久化（storage_write_config 已有基础设施）+ 接入 command/curve |
| MA-21 | **Major** | components/power_monitor/power_monitor.h:14-15 | `#define VOLTAGE_DIVIDER_5V 2.0f` / `VOLTAGE_DIVIDER_3V3 2.0f` | v1.2 硬件为 47k/10k=÷5.7 → 读数偏差 2.85 倍（10V 显示 2.8V 级错误）。**H-03 清单只改通道号不改分压比**——即使执行 H-03 电压仍然全错 | 常数改 5.7；头注释的分压网络描述同步更新 |
| MA-22 | **Major** | components/ota_handler/ota_handler.c 全文 + 协议 §7 | 无任何 `ota/status` MQTT 发布（进度仅 ESP_LOGI） | 协议 §7 状态反馈（state/progress_pct/message）固件端为零；web 亦未订阅 → OTAProgress 组件只有不确定动画 | ota_task 周期发布 ota/status；backend 订阅并转发 WS |
| MA-23 | **Minor** | main.c:122 | `snprintf(topic,...,"%s/%s/alert/cleared",...)` | `alert/cleared` topic 不在协议定义中，消费方（web/HA）均不处理 | 协议补录该 topic 或改用 alert+cleared 字段 |
| MA-24 | **Minor** | components/ds18b20/ds18b20.c:2,31-35 + ds18b20.h:2 | 头注释"RMT 精确时序"；实现为 GPIO bit-bang（`esp_rom_delay_us`），`driver/rmt_tx.h` 引入未用 | 注释失真；bit-bang 时序对中断抢占敏感（CRC8 可兜底丢数据但读数失败率升高）；800ms vTaskDelay 阻塞采集周期至 ~1.8s；parasite power 未显式拒绝 | 文档改口径；迁移 RMT 或至少关中断窗口；README 声明不支持 parasite |
| MA-25 | **Minor** | components/alert_manager/alert_manager.c:113-120 | Rule 2 无 clear 分支（temperature/voltage/wifi 均有） | fan_stall 告警恢复后规则仍 active、on_clear 永不触发 | 恢复 RPM 时 clear_rule(ALERT_TYPE_FAN_STALL) |
| MA-26 | **Minor** | main.c:217-228 | 只有 BME280 温度进入 alert_manager_update_temperature | 两路 DS18B20 探头（机箱关键温度）不参与温度告警 | 取三源最大值或分别设阈值 |
| MA-27 | **Minor** | alert_manager.c:37,92-94 | `s_wifi = true`（初值）；断连计时依赖 on_disconnected 回调 | 开机起从未连上 WiFi 时不产生 wifi_disconnected 告警（无断连事件） | 初始化为 false 或在 check_all 判 wifi_manager_is_connected() |
| MA-28 | **Minor** | components/wifi_manager/wifi_manager.c:307-317 | `nvs_erase_all(nvs)`（NS fan_ctrl） | "恢复出厂"只清 WiFi 凭据，不清 broker URL/曲线/日志 | 汇总各 NS 统一清理 |
| MA-29 | **Minor** | wifi_manager.c:277-282 | AP `.authmode = WIFI_AUTH_OPEN`，portal 无鉴权 | 局域网内任何人可改写 WiFi 凭据（deploy.md 声明的局域网假设未覆盖此点） | portal 加一次性 token 或最低限度的确认机制 |
| MA-30 | **Minor** | components/bme280/bme280.c:4-5,130-142 | 头注释声称"出错后 rm_device+重初始化"（无此代码）；calib 读取返回值未检查 | 注释失真；I2C 瞬时失败时静默使用垃圾校准值 | 检查返回值并 fail-fast；删除虚假注释 |
| MA-31 | **Minor** | main.c:45,61 | `char topic[64], payload[128]; ... (void)payload;` | 死代码 | 删除 payload |
| MA-32 | **Minor** | firmware/partitions.csv:4-5 + sdkconfig.defaults | factory 0x100000 / ota_0/1 0x180000 | factory 与 OTA 槽容量不对称（新固件>1MB 时 factory 无法作回退镜像）；coredump 分区存在但 CONFIG_ESP_COREDUMP 未启用 | 对齐三槽尺寸；启用 coredump 或删除该分区 |
| MA-33 | **Info** | fan_curve.c:157-162 | set_lut 不校验 temp_c 单调递增 | 乱序点导致插值行为异常 | 排序或拒绝乱序 |
| MA-34 | **Info** | mqtt_client_wrapper.c:161-166 | MQTT_EVENT_DATA 不处理分片（current_data_offset/total_data_len） | >4KB payload 会被截断解析（当前 payload 均小，暂无实害） | 加分片重组判断 |
| MA-35 | **Major** | main.c:354,158-157 | `mqtt_subscribe("fan-controller/+/command/#", ...)` ; handler 不校验 payload 内 device_id 与本机是否一致 | 通配 `+` 使设备收到**总线上所有设备**的命令且照单全收：多设备部署时一台设备的控制指令会被所有设备执行（当前唯一"受益者"是 ha 的 esp32-placeholder，见 MD-01——两个缺陷互相掩盖） | 订阅改 `{prefix}/{device_id}/command/#`，handler 再校验 device_id 字段 |

### 模块 B：agent

| 编号 | 严重度 | 文件:行 | 证据摘录 | 影响 | 建议修法 |
|---|:---:|---|---|---|---|
| MB-01 | **Critical** | agent/internal/monitor/gpu.go:6 + go.mod（§9.4-C 输出） | `import ( "bytes" ... )` — 全文无 bytes 使用；仓库无 go.sum | **编译失败（全平台）**：unused import；且干净检出无 go.sum 无法离线/CI 构建，`go mod tidy` 又因上游测试依赖 creack/gopty 仓库被删而失败 | 删除 bytes import；提交 go.sum（用 `go mod tidy -e` 生成）或 vendor |
| MB-02 | **Critical** | agent/cmd/agent/main.go:26-33 | `// TODO (T24): initialise MQTT client` / `// TODO (T23): ... collectors` / `// TODO (T24): ... USB relay` | **agent 是空壳**：加载配置后即挂起等信号，MQTT/采集/串口中继零功能；而 README/deploy.md 把它描述为已工作的 GPU 监控守护进程 | 完成接线（client.go/collector/relay 代码本身已存在且质量尚可） |
| MB-03 | **Major** | agent/install.sh:39 + agent/Makefile:23 | `install -Dm644 "${BINARY}.service"` → `smart-fan-agent.service`（仓库文件名为 `agent.service`） | 安装在 [4/4] 步必然 `set -e` 中止——**部署脚本从未成功跑通** | 统一文件名（建议 service 文件改名 smart-fan-agent.service） |
| MB-04 | **Major** | agent/internal/mqtt/client.go:47,75-76 | `topic := fmt.Sprintf("%s/+/command/#", ...TopicPrefix)` ; `"system-monitor/%s/sensor/%s", c.cfg.MQTT.ClientID` | 订阅命令偏离协议 §11（agent 应订阅 `+/sensor/#` 与 `+/alert`，未定义其消费 command）；发布 topic 用 ClientID 而非协议规定的 hostname | 订阅改 sensor/alert；发布用 os.Hostname() |
| MB-05 | **Major** | agent/agent.service:8-11 | `User=nobody` + `ReadWritePaths=/var/log/smart-fan-agent` | nobody 不在 dialout 组 → /dev/ttyACM0 打开必然 Permission denied（串口中继不可用）；且代码从不写 /var/log | 加 `SupplementaryGroups=dialout`；或指定专用用户 |
| MB-06 | **Minor** | agent/internal/config/config.go:38-48 + config.yaml:3 | `Port int \`yaml:"port"\`` — Port 从未被使用；broker URL 与 port 分离且无校验 | port 字段是死配置；填错 broker scheme 无提示 | 校验 broker URL 前缀；删除或合并 port |
| MB-07 | **Minor** | agent/internal/mqtt/client.go:64 | `if token.WaitTimeout(30*time.Second) && token.Error() != nil` | WaitTimeout 超时返回 false → 连接失败被当成功返回 | 改为 `!token.WaitTimeout(...) \|\| token.Error() != nil` |
| MB-08 | **Minor** | agent/internal/usb/relay.go:30-43 | `for attempt := 0; ; attempt++ { ... time.Sleep(delay) }` | Open() 永不返回错误：设备缺失时启动流程死等；且"读 ESP32 JSON 上报"与固件实现矛盾——固件 console 只应答命令、从不上报 JSON 行 | Open 有限次重试后返回错误；明确 relay 的架构定位或删除 |

### 模块 C：web

| 编号 | 严重度 | 文件:行 | 证据摘录 | 影响 | 建议修法 |
|---|:---:|---|---|---|---|
| MC-01 | **Critical** | web/frontend/package.json:7 + 目录盘点（§9.4-D） | `"build": "tsc && vite build"` — 无 tsconfig.json、index.html、src/main.tsx、vite.config.ts | `tsc` 打印帮助退出 1，`&&` 短路 → vite 从不执行，**dist 永不生成**；deploy.md §4.2/nginx/README 快速开始全部不可复现 | 补 tsconfig/vite.config/index.html/main.tsx 四件套 |
| MC-02 | **Critical** | web/backend/package.json:7 + §9.4-B | `"build": "tsc"` — backend 无 tsconfig.json | `npx tsc --noEmit` 打印帮助（无编译动作）；`npm start` 需要的 dist/server.js 无生成路径——**backend 无可用的构建/生产启动链**（dev 模式 tsx 可跑） | 补 tsconfig.json（module commonjs/outDir dist） |
| MC-03 | **Major** | web/backend/src/mqtt.ts:18,74 | `fans: Array.from({ length: 4 }, ...)` ; `if (idx >= 0 && idx < 4)` | 风扇数硬编码 4（表2）：v1.2 为 8 路；H-03 改 FAN_PWM_COUNT 后前端只显示 4 路 | 常量化并随设备上报的 fan 数量伸缩 |
| MC-04 | **Major** | web/backend/src/mqtt.ts:39-42 | 订阅仅 status/sensor/+/fan/+/state/alert | 协议 topic 中 `ota/status` 与 `*/buffered` 无消费方：OTA 进度、离线补发消息在前端不可见 | 补订阅 `+/ota/status`、`sensor/#` |
| MC-05 | **Major** | web/backend/src/routes/devices.ts:80-84 | `publishCommand(req.params.id, 'alert', {...})` | `command/alert` 不在协议 action 集（协议为 `config/alert`），固件亦无 handler → 该端点对设备是空操作却返回 applied:true | 改发 config/alert 并等固件实现 |
| MC-06 | **Major** | routes/devices.ts:52-57 + protocol.md §4.2 | CurveSchema: `pid: z.object({kp,ki,kd,setpoint_c})`（嵌套） | 协议 PID payload 为平铺（setpoint_c/kp/ki/kd 在顶层）；且 `temperature_source` 用字符串（"bme280"）而固件 fan_curve 是数字源 0-3，无任何映射层 | 与协议对齐（平铺）；定义字符串→源编号映射 |
| MC-07 | **Minor** | web/backend/src/server.ts:10,13 | `const PORT = ... 3001` ; `app.use(cors())` | 0.0.0.0 监听+CORS 全开+无鉴权；deploy.md 仅声明 broker 匿名为"局域网使用"，web 裸奔未声明 | deploy.md 补安全声明或加简单 token |
| MC-08 | **Minor** | routes/devices.ts:31-36 | `// In production: query Go Agent ... res.json(ok({ ..., entries: [] }))` | history 端点是占位空实现，History 页的时间范围选择不触发任何后端查询 | 接通 agent 或固件 storage_get_recent_logs 通道 |
| MC-09 | **Minor** | grep（§9.4-G） | pages/ 对 components/ 的 import 数为 0 | components/ 下 7 个组件全部死代码（页面各自内联重实现，两套 FanCard/CurveEditor 行为已开始分叉） | 统一抽回 components 并删除页面内联版 |
| MC-10 | **Minor** | components/CurveEditor.tsx:92-114 + Fans.tsx:125-134 | 点位 input 无 0-100 校验、无增删点 UI（固定 5 点） | 用户可输入 200% 占空比/乱序温度；协议未定义点数上限（firmware FAN_CURVE_MAX_POINTS=10）两边不校验 | 输入 clamp + 点数上限统一为 10 |
| MC-11 | **Major** | web/frontend/src/pages/Alerts.tsx:15,93 | `const SEV_COLORS = { 0:'#22c55e', 1:'#f59e0b', 2:'#ef4444' }` ; `SEV_COLORS[a.alert_type]` | 把 alert_type（0=温度,1=停转,2=电压,3=wifi）误当 severity 用：**温度告警显示绿点、wifi 告警无色**；根因是 MA-10 缺 severity 字段 | 固件补 severity 字段后前端按 severity 取色 |
| MC-12 | **Minor** | web/frontend/src/pages/History.tsx:95 + Fans.tsx:22 | `new Date(a.timestamp * 1000)` | 因 MA-12（timestamp=uptime），告警时间显示 1970+开机时长；History 仅跟踪 fan0/fan1 两路 | 随 MA-12 修复；补足 8 路序列 |
| MC-13 | **Minor** | pages/Fans.tsx:17-23 内联 FanCard | `const [duty, setDuty] = useState(fanState.pwm_duty_pct)` | 滑块初值后不随设备推送更新（stale state）；onMouseUp 提交不支持触摸拖动 | useEffect 同步或受控回显 |

### 模块 D：ha

| 编号 | 严重度 | 文件:行 | 证据摘录 | 影响 | 建议修法 |
|---|:---:|---|---|---|---|
| MD-01 | **Critical** | ha/fans.yaml:6,24 | `command_topic: "fan-controller/esp32-placeholder/command/fan"` | 占位 device_id：命令发往不存在的 `esp32-placeholder`——真实设备 ID 永不匹配；当前之所以"碰巧能通"全靠固件 MA-03/MA-14 的通配订阅缺陷，修复固件后 HA 控制立即断链 | 文档化 device_id 获取方式（status topic），模板化或安装时替换 |
| MD-02 | **Major** | ha/fans.yaml 全文 | 仅 "Fan 0"/"Fan 1" 两个实体 | 控制实体 2 个 vs RPM 传感器 4 个（sensors.yaml）vs 固件 4 路 vs v1.2 8 路——四层口径互不相同（表2）；ha/README.md:36 声称"风扇 0-3 转速控制"亦与 2 实体不符 | 路数统一后按实际数量生成 |
| MD-03 | **Major** | ha/alerts.yaml:7-8 | `{{ 'ON' if value_json.alert_type == 0 else 'OFF' }}` | 四个 binary_sensor 共用同一 state_topic、按消息内容即时翻转：**任何一条告警到达都会把其余三个传感器打成 OFF**；告警恢复也无对应消息（固件 alert/cleared 是另一 topic 且无人消费） | 固件发独立的 per-type 状态 topic，或使用 device_trigger/事件模型 |
| MD-04 | **Minor** | ha/sensors.yaml:47 | `value_template: "{{ value_json.sensors[0].temperature_c }}"` | 按数组位置取探头：固件跳过 invalid 传感器（main.c:238）导致索引移位、贴错标签；第二探头无实体；3.3V 电压无实体 | 固件按协议发 address/valid 后按地址匹配；补实体 |
| MD-05 | **Minor** | ha/*.yaml 全文 | 无任何 `availability_topic` | 协议 §8 要求 LWT 联动可用性（plan §5 检查点）；设备离线后实体状态停留在旧值 | 各实体加 availability_topic=`fan-controller/{id}/status`+availability 模板 |

### 模块 E：test

| 编号 | 严重度 | 文件:行 | 证据摘录 | 影响 | 建议修法 |
|---|:---:|---|---|---|---|
| ME-01 | **Critical** | test/smoke_test.sh:7,17 + test/e2e/integration_test.sh:5,12 | `set -euo pipefail` + `pass() { echo ...; ((PASS++)); }` | `((PASS++))` 首次求值为 0 → 算术命令退出码 1 → **脚本在第一个通过的检查处立即退出（exit 1）**，后续检查全部不执行 | 改 `((++PASS))` 或 `PASS=$((PASS+1))` |
| ME-02 | **Major** | test/e2e/integration_test.sh:62-69 | T4 注释"verify device receives"，实际只 publish 后判成功，`T_OUT=$(mktemp)` 创建后从未读取 | 命令是否被设备接收/执行零验证——断言质量失真 | sub 捕获 payload 并断言字段；删无用 mktemp |
| ME-03 | **Minor** | test/smoke_test.sh:3,113-119,143-146 | 头部声明依赖 jq（全文未使用）；CP7 的 SUB_OUT 未校验；CP12 的 TOPICS 变量计算后弃用（且 `grep -c "Topic:"` 对 `**Topic**:` 实际匹配 0） | 依赖声明与断言均有水分；CP11/CP12 依赖相对路径，必须从仓库根运行但未说明 | 删 jq；补 SUB_OUT 内容断言；头部注明工作目录 |
| ME-04 | **Info** | smoke_test.sh CP1-CP10 vs 协议 | 覆盖：status/sensor/fan state/command fan/alert/OTA 触发/校验 | 协议命令 curve、reset、config、ota/status、buffered 均无任何测试（覆盖表见 §9.3 表3 附注） | 补测 |

### 模块 F：docs 与仓库根

| 编号 | 严重度 | 文件:行 | 证据摘录 | 影响 | 建议修法 |
|---|:---:|---|---|---|---|
| MF-01 | **Major** | README.md:7,72,150 | "4-channel PWM"、"4路独立风扇"、"4路 4Pin 25kHz PWM" | 与 v1.2 硬件（D2=8 路）矛盾——R6 数字矛盾；注意整改清单 H-07 描述为"README 6路→8路"，实际现状是 4 路，整改执行者会被误导 | H-07 执行时以现状 4→8 为准 |
| MF-02 | **Major** | README.md:16,157 + docs/index.html:177,282,293 | `[PCB-80×60mm_2Layer]` / "80mm × 60mm，双层 FR4" | v1.2 决策 D3 为 99×99mm 4 层；index.html（GitHub Pages 门面）同错 | 随 H-07 一并更新 |
| MF-03 | **Major** | README.md:137,222 + ha/README.md:15 | "HA 自动发现设备，无需手动配置"/"固件启动后会自动发布 Discovery 消息" | 固件 grep `homeassistant` 为零（§9.4-F）——**Discovery 完全未实现**，文档承诺虚假；README 同页又给出手动 packages 步骤，两种说法并存 | 删除自动发现表述或实现 discovery 发布 |
| MF-04 | **Major** | docs/deploy.md:63-69,233 + docs/hardware-assembly.md:166-176 | `fan 0 speed 75`、`fan 0 auto`、`wifi status`；验收示例 help 输出含 "fan" | 固件 console 实际命令仅 help/status/reboot/ota（usb_console.c:145-146 + main.c:377-378）——**文档教的命令全部不存在**，组装验收流程照做必然失败 | deploy/assembly 文档命令表对齐实现（或补固件 fan/wifi 命令） |
| MF-05 | **Minor** | README.md:181,186,252 | "USB-CDC（6+命令…）"、"12个 Unity 单元测试"、`cd web && npm test` | 实际 4 命令、13 个测试文件且未接入构建、web 根无 package.json（npm test 报错） | 数字与命令对齐；测试接入 CMake 或删述 |
| MF-06 | **Minor** | docs/deploy.md:216-218 | `-t "fan-controller/esp32-XXXXXX/command/ota"` | deploy 记载的 OTA topic 与固件实现一致但与协议 §7（`{id}/ota`）不一致——实现/文档/协议三方分裂的实证（表1） | 借协议修订统一口径 |
| MF-07 | **Minor** | docs/hardware-assembly.md 全文 | J3-J6 四路风扇座、R13-R24 12 只 Tach 电阻、D3 SRV05-4、F1 MF-MSMF250、J7/J8 探头位号 | 整体为 v1.1 口径（8 路/24 电阻+8 电容/D3 二极管或/F1≥3A/J11/J12 均不符）——与 H-07 待改清单一致，作为整改前基线记录 | 执行 H-07 重写 |
| MF-08 | **Minor** | .omo/ 与 .sisyphus/ | `diff -rq` 输出为空（字节级相同），163K×2，均被 git 跟踪 | 同一份数据双份入库（历史 AI 执行计划+任务证据）；.gitignore 仅注释性提及 | `git rm -r` 保留一份或全部移出并加 ignore |
| MF-09 | **Minor** | hardware/docs/hardware-design-guide-v1.1.md:573-576 | `bom-main-board-v1.1.xlsx / bom-expansion-board-v1.0.xlsx / pcb-layout-example.png / test-procedure.md` | 附录引用的 4 个文件均不存在（死链，H-16 范围）；注：`hardware/BOM.csv` 实际**存在**（审查计划所列"已知死链"有误），但为 v1.1 旧口径 | 执行 H-16；计划文档该条勘误 |
| MF-10 | **Info** | LICENSE + 各模块 | 根 MIT（© 2026 OneAsmallFish），agent/web 无独立 license | 与 README 徽章一致，无冲突 | 无需动作 |

---

## 9.3 一致性矩阵（§8 六张表）

### 表1 MQTT topic（左列 = protocol.md 全部 topic 完整枚举）

| # | protocol.md topic（行号） | QoS/方向（协议） | firmware 实现 | web backend | agent | ha | 一致? |
|---|---|---|---|---|---|-----|:-----:|
| 1 | `fan-controller/{id}/status`（:26,47,72） | 1 / 设备→Broker, LWT retain | ✓ pub（LWT:219 仅 status 字段；online:137 缺 4 字段 → MA-11） | ✓ 订阅 `+/status`（mqtt.ts:39） | ✗ 未实现（空壳） | ✓ 订阅（alerts.yaml:39） | ⚠ 字段不全 |
| 2 | `fan-controller/{id}/sensor/bme280`（:27,83） | 0 / 设备→Broker | ✓ pub 1s QoS0 ✓字段 | ✓ 订阅消费 | ✗ | ✓ 订阅 | ✓ |
| 3 | `.../sensor/ds18b20`（:27,98） | 0 / 设备→Broker | ⚠ pub 字段 index≠协议 address/valid（MA-28 关联） | ✓ 消费（按 index） | ✗ | ⚠ 按位置[0]取值 | ⚠ schema |
| 4 | `.../sensor/voltage`（:27,114） | 0 / 设备→Broker，**5s** | ⚠ pub 1s（频率不符，MA-29） | ✓ | ✗ | ✓（缺 3v3 实体） | ⚠ 频率 |
| 5 | `.../sensor/internal_temp`（:27,129） | 0 / 设备→Broker，**5s** | ⚠ pub 1s | ✓ | ✗ | ✓ | ⚠ 频率 |
| 6 | `.../fan/{index}/state`（:28,146）index 0-3 | 0 / 设备→Broker | ✓ pub 1s QoS0；缺 mode 字段（MA-16） | ✓ 订阅（idx<4 硬编码） | ✗ | ✓（fan/0-3） | ⚠ 字段 |
| 7 | `.../command/fan`（:29,173） | 1 / Broker→设备 | ✓ 处理（158-164）——但订阅链路断（MA-03） | ✓ 发布（devices.ts:44） | ✗ 订阅的是整个 command/# | ✓ payload_on/off/percentage 模板 | ⚠ 订阅断 |
| 8 | `.../command/curve`（:29,189） | 1 | ✗ **无 handler**（MA-09） | ✓ 发布（嵌套 PID schema 偏差 MC-06） | ✗ | — | ✗ |
| 9 | `.../command/reboot`（:29,225） | 1 | ✓ 处理（171-175） | ✓ 发布 | ✗ | — | ✓（链路受 MA-03 影响） |
| 10 | `.../command/reset`（:29,236） | 1 | ✗ 无 handler | ✗ 无端点 | ✗ | — | ✗ 双缺失 |
| 11 | `.../alert`（:30,250） | 1 / 设备→Broker | ⚠ pub（alert_type 数字、缺 severity/sensor，MA-10） | ✓ 订阅（按数字解析） | ✗ | ✓ 订阅（数字匹配） | ⚠ schema |
| 12 | `.../alert/cleared`（**协议未定义**） | — | ✓ 固件发布（main.c:122） | ✗ 不消费 | ✗ | ✗ | ✗ 幽灵 topic |
| 13 | `.../config/{wifi,mqtt,alert,curve}`（:31,281-306） | 1 / 双向 | ✗ 不订阅不发布 | ✗ 不订阅（alert 规则误发 command/alert，MC-05） | ✗ | — | ✗ 全线未实现 |
| 14 | `.../ota`（:32,312） | 1 / Broker→设备 | ✗ 固件不订阅此 topic（只听 command/ota） | ✗ 发的是 command/ota | ✗ | — | ✗ 三方分裂（deploy.md:217 站固件侧） |
| 15 | `.../ota/status`（:326） | 1 / 反馈 | ✗ 从不发布（MA-22） | ✗ 不订阅 | ✗ | ✗ | ✗ 全线未实现 |
| 16 | `homeassistant/{component}/{id}/{object}/config`（:33,351-390） | 1 / Discovery | ✗ 固件零 discovery 代码（MA-23） | — | — | —（ha/ 走手动 packages） | ✗ |
| 17 | `.../sensor/.../buffered`（:440-443） | — | ✗ 无后缀直发（MA-15） | ✗ `sensor/+` 匹配不到 5 级 topic | ✗ | ✗ | ✗ 全线未实现 |
| 18 | `system-monitor/{hostname}/sensor/gpu`（:470） | 0 / agent→Broker | — | — | ⚠ 代码用 ClientID 而非 hostname（MB-04），且 main 空壳未接线 | — | ⚠ |
| 19 | （固件私有）订阅 `fan-controller/+/command/#`（main.c:354） | — | ⚠ 通配+不校验 device_id（MA-14）；且因 MA-03 实际未生效 | — | ⚠ agent 同样订阅 command/#（协议未授权） | — | ✗ |

### 表2 风扇数量与索引（左 = 硬件 v1.2 = 8 路）

| 位置 | 数值 | file:line | 0/1-based | 与 8 路一致? |
|---|:----:|---|:---:|:---:|
| 硬件 v1.2（整改清单 D2） | **8** | remediation §1（GPIO5-12, 13-15/21/38-41） | Fan1=index0（:65） | 基准 |
| firmware FAN_PWM_COUNT | 4 | fan_pwm.h:9 | 0-based | ✗ |
| firmware FAN_TACH_COUNT | 4 | fan_tach.h:10 | 0-based | ✗ |
| firmware FAN_CURVE_FANS | 4 | fan_curve.h:10 | 0-based | ✗ |
| firmware main 循环 | 4（字面量） | main.c:280,301 | 0-based | ✗（且未用宏，H-03 连带） |
| firmware alert 数组 | 4 | alert_manager.c:35,87,113 | 0-based | ✗ |
| firmware 日志缓冲 | fan_rpm[4] | flash_storage.h:17 | 0-based | ✗ |
| protocol.md | 4（index 0,1,2,3） | protocol.md:37 | 0-based | ✗ 文档待更新 |
| web backend | 4 | mqtt.ts:18,74 | 0-based | ✗ |
| web Fans 页注释 | "4路" | Fans.tsx:1 | 0-based（"Fan 0"） | ✗ |
| web History 页 | 2（仅 fan0/fan1 曲线） | History.tsx:35-36,98-99 | 0-based | ✗ |
| ha fans.yaml 控制实体 | **2** | fans.yaml:4,22 | 0-based（"Fan 0/1"） | ✗ |
| ha sensors.yaml RPM | 4 | sensors.yaml:88-122 | 0-based | ✗ |
| ha README 声称 | 控制 4（"风扇 0-3"） | ha/README.md:36 | 0-based | ✗ 且与自身 2 实体矛盾 |
| README.md | 4 | README.md:7,72,150 | 0-based | ✗ |

**结论：全项目 15 处路数口径 = {2,4,4,4,...}，无一处为 8；索引风格 0-based 全局统一 ✓。**

### 表3 命令名与 payload（左 = usb_console 实际命令表 + protocol 命令并集）

| 命令 | 固件 usb_console | 固件 MQTT handler | protocol.md §4 | web backend | ha | deploy/assembly 文档 | 一致? |
|---|---|---|---|---|-----|---|:-----:|
| help | ✓（usb_console.c:145） | — | —（协议不定义 console） | — | — | ✓ 记载 | ✓（但 assembly:175 的 help 输出示例含不存在的 "fan"） |
| status | ✓（main.c:377） | — | — | — | — | ✓ | ✓ 字段一致（assembly:168 示例与 cmd_status 输出吻合） |
| reboot | ✓（usb_console.c:146） | ✓ command/reboot | ✓ §4.3 | ✓ POST /reboot | — | ✓ | ✓ |
| ota | ✓（main.c:378） | ⚠ command/ota（协议为 /ota） | ✓ §7（firmware_url/version/checksum） | ✓（仅 firmware_url，缺 version/checksum） | — | ✓ | ⚠ topic 位置+字段 |
| fan | ✗ **不存在** | ✓ command/fan（fan_index/duty_pct；忽略 mode 语义） | ✓ §4.1 | ✓（speed→duty_pct ✓ 0-100 校验 ✓） | ✓ payload/percentage 模板 | ✗ deploy.md:64-66、assembly:170 教用 | ✗ 文档虚构 |
| wifi | ✗ 不存在 | — | — | — | — | ✗ deploy.md:233 `wifi status` | ✗ 文档虚构 |
| curve | — | ✗ 无 handler | ✓ §4.2（LUT points / PID 平铺） | ⚠ 嵌套 PID + 字符串 temperature_source | — | — | ✗ schema 三方两版 |
| reset | — | ✗ 无 handler | ✓ §4.4（confirm） | ✗ 无端点 | — | — | ✗ 双缺失 |
| config/alert | — | ✗ 不订阅 config/# | ✓ §6.2 | ⚠ 发 command/alert（错位） | — | — | ✗ |

**测试覆盖附注（ME-04）**：smoke 覆盖 fan 命令链路（CP7）与 OTA 触发（CP9）；curve/reset/config/ota/status/buffered 零测试。

### 表4 传感器类型与单位（左 = protocol.md §2 完整枚举）

| 传感器/字段 | protocol.md | firmware 上报 | web backend/前端 | ha | 一致? |
|---|---|---|---|-----|:-----:|
| bme280.temperature_c (°C) | :91 | ✓ main.c:224 | ✓ types.ts:3 / Dashboard | ✓ sensors.yaml:10-11 | ✓ |
| bme280.humidity_pct (%) | :92 | ✓ | ✓ | ✓ device_class humidity | ✓ |
| bme280.pressure_hpa (hPa) | :93 | ✓ | ✓ | ✓ | ✓ |
| ds18b20.sensors[].address ("28-..") | :106 | ✗ 发 index（main.c:240） | ✗ types.ts:10 index | ✗ 位置[0] | ✗ |
| ds18b20.sensors[].valid (bool) | :106 | ✗ 无效项直接跳过不报 | ✗ 无 | ✗ 无 | ✗ |
| ds18b20.sensors[].temperature_c | :106 | ✓ | ✓ | ✓ | ✓ |
| voltage.voltage_12v (V) | :121 | ✓（值错 ÷5.7，MA-21） | ✓ VoltageBar 12V±10% | ✓ | ⚠ 数值精度 |
| voltage.voltage_5v (V) | :122 | ✓（值错） | ✓ ±5%=±0.25 与固件容差一致（Dashboard:93） | ✓ | ⚠ |
| voltage.voltage_3v3 (V) | :123 | ✓（值错） | ✓ ±5%=±0.165（Dashboard:94） | ✗ 无实体 | ⚠ |
| internal_temp.temperature_c (°C) | :136 | ✓ | ✓ | ✓ | ✓ |
| fan.pwm_duty_pct (0-100) | :162 | ✓ | ✓ | ✓（percentage_value_template） | ✓ |
| fan.rpm | :163 | ✓ | ✓ | ✓ | ✓ |
| fan.stalled (bool) | :164 | ✓（判定 rpm<200&&duty>5，与固件告警口径不同） | ✓ | —（仅 RPM 实体） | ✓ |
| fan.mode ("auto"/"manual") | :165 | ✗ 不发布（MA-16） | 类型有、值恒 'auto' | — | ✗ |
| alert.severity ("warning"/"critical") | :257-273 | ✗ 不发布（MA-10） | ✗ 无字段（误用 alert_type 上色） | ✗ 无 | ✗ |
| timestamp（Unix 秒） | :13 | ✗ 开机秒（MA-12） | History 按 epoch 展示 → 1970 年 | — | ✗ |
| 上报频率 bme280/ds18b20=1s, voltage/internal=5s | :84,99,116,131 | 1s/1s/1s/1s | — | — | ⚠ voltage/internal 快 5 倍 |

### 表5 告警级别（左 = firmware alert_manager）

| 维度 | firmware | protocol.md §5/§6.2 | web 前端 | ha/alerts.yaml | 一致? |
|---|---|---|---|---|:-----:|
| 级别模型 | 3 级枚举 NORMAL/WARNING/CRITICAL（alert_manager.h:9） | 2 值字符串 warning/critical（:271） | SEV_COLORS {0绿,1黄,2红} 但**键是 alert_type**（Alerts.tsx:15） | 无级别概念（binary on/off） | ✗ 四方四种口径 |
| alert_type 表示 | 数字 0-3 | 字符串 4 种（:265-269） | 数字（跟随固件） | 数字比较 ==0/1/2（:8,19,30） | ✗ 类型+表达 |
| 阈值 temperature_high | 75°C 警告 / >80°C critical（alert_manager.c:13,103） | 示例 78.5°C 即 critical（:257） | 默认 75（AlertRuleEditor:11） | — | ⚠ critical 门限不一致 |
| 阈值 fan_stalled | <200RPM（且 rpm>0 才判，MA-06） | 示例 200（:302） | 默认 200 ✓ | — | ⚠ 判定逻辑 |
| 阈值 voltage_abnormal | 12V 10.8-13.2 / 5V ±0.25 / 3.3V ±0.165（:15-18） | 12v_min 10.8 + 12v_max 13.2（:303） | 单阈值 10.8（丢 max）（AlertRuleEditor:13）；Dashboard 判定与固件完全一致（:92-94） | — | ⚠ 单/双阈值 |
| 阈值 wifi_disconnected | >60s（:19） | 60s（:269） | 默认 60 ✓ | — | ✓ |
| 阈值可配置性 | 全部硬编码（config 通道未实现） | §6.2 定义运行时可配 | UI 可编辑但发到无人处理的 command/alert | — | ✗ 功能断链 |
| LED 颜色映射 | status_led.h:11-16（绿呼吸/黄慢闪/红快闪/蓝慢闪/紫呼吸） | §5 黄/红 两档 ✓ | — | — | ✓（协议仅覆盖两档） |

### 表6 硬件引脚（左 = 整改清单 §1 v1.2 权威表全 34 行；H-03 未执行）

| GPIO | v1.2 功能 | 固件 define/用法（file:line） | 一致? |
|:----:|---|---|:-----:|
| EN | RESET，10k 上拉+SW1 | （无显式 define，依赖模组默认） | — |
| 0 | BOOT strapping | 未用 | ✓ |
| 1 | ADC_12V（CH0，÷6） | power_monitor.c:16 `CH_3V3=ADC_CHANNEL_0 /*GPIO1*/` | ✗ 功能错位 |
| 2 | ADC_5V（CH1，÷5.7） | power_monitor.c:17 `CH_5V=ADC_CHANNEL_1 /*GPIO2*/` | ✓ |
| 3 | **NC**（strapping 禁接） | power_monitor.c:18 `CH_12V=ADC_CHANNEL_2 /*GPIO3*/` | ✗ 违规占用 |
| 4 | ADC_3V3（CH3，÷5.7） | fan_pwm.c:23 `FAN_GPIO[0]=4`（v1.1 遗留）；ADC 侧未用 | ✗ 双重冲突 |
| 5 | FAN1_PWM | fan_pwm.c:23 ✓（LEDC_CH1 位） | ✓ 位置对、序号偏移见 H-03 |
| 6 | FAN2_PWM | fan_pwm.c:23 ✓ | ✓ |
| 7 | FAN3_PWM | fan_pwm.c:23 ✓ | ✓ |
| 8 | FAN4_PWM | fan_tach.c:16 `TACH_GPIO[0]=8` | ✗ PWM/Tach 冲突 |
| 9 | FAN5_PWM | fan_tach.c:16 TACH=9 | ✗ 冲突 |
| 10 | FAN6_PWM | fan_tach.c:16 TACH=10 | ✗ 冲突 |
| 11 | FAN7_PWM | fan_tach.c:16 TACH=11 | ✗ 冲突 |
| 12 | FAN8_PWM | 未用 | ✗ 缺失 |
| 13 | FAN1_TACH PCNT_U0_CH0 | 未用 | ✗ 缺失 |
| 14 | FAN2_TACH PCNT_U0_CH1 | 未用 | ✗ 缺失 |
| 15 | FAN3_TACH PCNT_U1_CH0 | 未用 | ✗ 缺失 |
| 16 | DS18B20_DQ | ds18b20.c:20 `OW_GPIO 16` ✓ | ✓ |
| 17 | I2C_SDA | bme280.c:16 `I2C_SDA_GPIO 17` ✓ | ✓ |
| 18 | I2C_SCL | bme280.c:17 `I2C_SCL_GPIO 18` ✓ | ✓ |
| 19 | USB_D- | TinyUSB 隐式使用（usb_console） | ✓（隐式） |
| 20 | USB_D+ | 同上 | ✓（隐式） |
| 21 | FAN4_TACH PCNT_U1_CH1 | 未用（v1.2 特意把 21 用作 PCNT；固件不知情） | ✗ 缺失 |
| 38 | FAN5_TACH PCNT_U2_CH0 | wifi_manager.c:34 `BTN_GPIO 38` | ✗ 按键/测速冲突 |
| 39 | FAN6_TACH PCNT_U2_CH1 | 未用 | ✗ 缺失 |
| 40 | FAN7_TACH PCNT_U3_CH0 | 未用 | ✗ 缺失 |
| 41 | FAN8_TACH PCNT_U3_CH1 | 未用 | ✗ 缺失 |
| 42 | SPI_SCK（屏幕预留） | 未用 | —（屏幕未实现） |
| 43 | SPI_MOSI（屏幕预留） | 未用；⚠ sdkconfig 未改默认 console=UART0，日志仍走 43/44 | ⚠ 隐患（MA-34） |
| 44 | SPI_CS（带上拉） | 同上 | ⚠ |
| 45 | WS2812B_DI | status_led.c:15 `LED_GPIO 48` | ✗ |
| 46 | NC（strapping） | 未用 | ✓ |
| 47 | BTN_WIFI_CFG | 未用（固件按键在 38） | ✗ |
| 48 | SPI_DC（屏幕预留） | status_led.c:15 占用 48 | ✗ |

**汇总：34 行中 ✗ 16 行、⚠ 3 行、✓ 12 行、— 3 行。一致率 35%（12/34）。** 引脚层面的全部 ✗ 均并入 MA-07（H-03 未执行），但 MA-21（分压比）与 MA-34（console 路由）为 H-03 清单未覆盖的增量项。

---

## 9.4 执行证据

### A. 固件构建 — BLOCKED

```
$ command -v idf.py → NOT FOUND；env | grep -i idf → (空)
```
`idf.py build` **BLOCKED：本机无 ESP-IDF 环境**。静态替代验证：MA-01/MA-02 为无需编译器即可判定的语法/依赖错误（C 语言层面成立）；其余固件结论均为全文代码审查所得，未做运行验证。

### B. web backend — 失败（无 tsconfig）

```
$ cd web/backend && npm install && npx tsc --noEmit
added 135 packages in 37s
（随后输出 tsc 通用帮助文本 ~140 行）→ 退出码 1
```
判定：目录无 tsconfig.json，tsc 无输入可编译。**补充验证**（显式参数）：
```
$ npx tsc --noEmit --esModuleInterop --module commonjs --target es2022 \
    --moduleResolution node --strict --skipLibCheck src/server.ts
→ 退出码 0（源码本身类型干净，问题纯在构建配置缺失）
```

### C. agent — 失败（两条独立证据）

```
$ cd agent && go build ./... && go vet ./...
internal\config\config.go:8:2: missing go.sum entry for module providing package gopkg.in/yaml.v3 ...
internal\mqtt\client.go:12:2: missing go.sum entry ... github.com/eclipse/paho.mqtt.golang
internal\usb\relay.go:11:2: missing go.sum entry ... go.bug.st/serial
```
临时副本 `go mod tidy -e`（不触碰仓库）后：
```
internal\monitor\system.go:136:19: undefined: syscall.Statfs_t        ← Windows 宿主，Linux 目标合法
internal\monitor\gpu.go:6:2: "bytes" imported and not used            ← 全平台编译错误
```
Linux 交叉编译 `GOOS=linux GOARCH=amd64 go build`：仍因 go.sum 缺传导依赖 `github.com/creack/goselect` 失败（其同族测试依赖 `creack/gopty` 上游仓库已被删除，普通 `go mod tidy` 无法自愈）。

### D. web frontend — 失败

```
$ cd web/frontend && npm run build ; echo EXIT=$?
> tsc && vite build
（tsc 帮助文本） → EXIT CODE: 1
```
`tsc` 退出 1 → `&&` 短路 → **vite build 从未执行**；且目录盘点确认无 `index.html`、`src/main.tsx`、`vite.config.ts`、`tsconfig.json`（vite 四要素全缺）。首轮流水分 析中 "FRONTEND BUILD DONE" 系管道吞掉退出码的假象，已用无管道重跑纠正。补充：显式参数 tsc 对 5 页面+App 类型检查退出码 0。

### E. H-03 执行状态 grep（整改清单 §H-03 验收命令原文照跑）

```
$ grep -rn "{ 4, 5, 6, 7 }" firmware/
firmware/components/fan_pwm/fan_pwm.c:23:static const int FAN_GPIO[FAN_PWM_COUNT] = { 4, 5, 6, 7 };   ← 非空
$ grep -rn "FAN_PWM_COUNT 4\|FAN_TACH_COUNT 4" firmware/
fan_pwm.h:9 / fan_tach.h:10                                                                            ← 非空
$ grep -n "LED_GPIO         48" status_led.c   → 15: 命中                                              ← 非空
$ grep -n "BTN_GPIO        38" wifi_manager.c  → 34: 命中                                              ← 非空
$ grep -rn "ADC_CHANNEL_2" power_monitor/      → :18 命中                                              ← 非空
```
**结论：H-03 五条验收全部不通过 → 整改未执行**（并入 MA-07）。

### F. 死代码/幽灵功能 grep（零调用方证实）

```
$ grep -rn "ota_handler_confirm_mqtt|fan_curve_set_lut|fan_curve_set_pid|fan_curve_set_temp_source|
           storage_write_config|power_monitor_on_power_fail" firmware/ --include=*.c --include=*.h
→ 上述符号仅剩 .h 声明 + .c 定义 + firmware/test/ 引用，main.c/组件运行路径零调用
$ grep -rn "homeassistant" firmware/ → 0 命中（Discovery 未实现实证）
$ grep -rn "availability" ha/ firmware/ web/backend/src/ → 0 命中
$ grep -rn "from '.*components/" web/frontend/src/pages/ → 0 命中（7 组件死代码实证）
```

### G. 语法/解析校验 — 通过

```
$ bash -n test/smoke_test.sh          → OK
$ bash -n test/e2e/integration_test.sh → OK
$ python -c "import yaml,glob; [yaml.safe_load(...) for f in glob.glob('ha/*.yaml')]" → YAML OK
```

### H. 其他盘点证据

```
$ diff -rq .omo .sisyphus → 无输出（字节级相同，退出码 0）；du：各 163K
$ wc -l（86 文件全量行数）→ 见 §9.1 覆盖矩阵
死链核验：bom-main-board-v1.1.xlsx / bom-expansion-board-v1.0.xlsx /
          pcb-layout-example.png / test-procedure.md → MISSING×4；
          hardware/BOM.csv → EXISTS（计划"已知死链"条目勘误，见 MF-09）
$ ls firmware/test/*.c | wc -l → 13；CMakeLists 无 test 引用 → 测试不参与构建
```

---

## 9.5 统计与结论

### 发现分桶

| 严重度 | 数量 | 编号 |
|:---:|:----:|---|
| Critical | 12 | MA-01,02,03,04,05,06 / MB-01,02 / MC-01,02 / MD-01 / ME-01 |
| Major | 32 | MA-07~22,35（17 项）/ MB-03,04,05 / MC-03,04,05,06,11 / MD-02,03 / ME-02 / MF-01,02,03,04 |
| Minor | 27 | MA-23~32（10 项）/ MB-06,07,08 / MC-07,08,09,10,12,13 / MD-04,05 / ME-03 / MF-05,06,07,08,09 |
| Info | 4 | MA-33,34 / ME-04 / MF-10（另：表4 中 voltage/internal_temp 上报频率偏差已并入 MA-29） |

编号规则：MA=firmware、MB=agent、MC=web、MD=ha、ME=test、MF=docs 与仓库根，共 75 条。

### 覆盖完成声明

- §2~§7 全部文件清单 **100% 逐文件全文审查**，覆盖矩阵无空行、无"抽样"。
- §8 六张矩阵左侧完整枚举：表1=19 行（协议全部 topic+实现私有 topic）、表2=15 处路数、表3=9 条命令、表4=17 项字段、表5=8 个维度、表6=34 行引脚（整改清单 §1 全表）。
- R6 数字矛盾全部登记：风扇路数 {2,4,8}、alert_type/severity 类型、timestamp 语义、PID payload 结构、曲线 temperature_source 字符串/数字、critical 门限 78.5/80、单/双电压阈值、`((PASS++))` 等。

### BLOCKED 清单

| 项 | 原因 | 后续 |
|----|---|---|
| `idf.py build` | 审查机无 ESP-IDF | 在有 IDF v5.3+ 的环境复跑；预计先撞 MA-01/02 |
| agent Linux 原生运行验证 | 仅交叉编译（且被 go.sum 阻断） | 补 go.sum 后在 Linux CI 复跑 |
| 真机端到端（MQTT/风扇/OTA） | 无硬件 | 固件编译修复后进行 |

### 结论与整改优先级建议

1. **P0（先让"能构建"成立）**：MA-01/02（固件编译）、MB-01（agent 编译+go.sum）、MC-01/02（web 构建配置）、ME-01（测试脚本自毁）。这 7 项不修，任何后续整改都无法验证。
2. **P0（执行中的硬件整改前置）**：H-03 按 MA-07 的扩展清单执行（原清单 + 分压比 ÷5.7 + PCNT unit=i/2 + 五处硬编码 4 + console 路由）。
3. **P1（通信链路）**：MA-03/04/14（订阅与回调）、MA-05（OTA 回滚）、MA-11/12（LWT/timestamp）、MD-01（占位 device_id）。
4. **P1（协议对齐）**：以表1/表3/表4 为对照单，一次性裁决"协议改还是实现改"（建议：alert schema、ota topic 位置、curve PID 结构、ds18b20 address 字段——协议向实现对齐成本低；timestamp/Unix 秒——实现向协议改）。
5. **P2**：死代码清理（components/×7、relay 定位）、文档口径统一（MF-01~04）、.omo/.sisyphus 去重。

---

**报告版本：** v1.0（2026-08-24）
**审查计划：** `docs/module-review-plan.md` v1.0
**上游文档：** `hardware/docs/remediation-plan-v1.2.md`（H-03 状态：**未执行**，证据 §9.4-E）

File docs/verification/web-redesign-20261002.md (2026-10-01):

# Web 控制台现代化重构验收记录（2026-10-02）

> 范围：frontend 全量重构（i18n / 设计 token / 风扇交互 / 真实历史）+ backend 小改（曲线回读缓存、/health mqtt、历史环形缓冲）。
> 设计参照：THRM（TIANLI0/BS2PRO-Controller）glacier 主题与曲线交互，静态取证见会话记录。

## 交付内容

| 项 | 说明 |
|---|---|
| i18n | react-i18next，zh-CN（默认）/ en-US 双语，侧栏切换，localStorage 持久化，`<html lang>` 同步；全站零硬编码文案 |
| 设计系统 | Tailwind CSS 4 + CSS 变量双基底（暗默认/亮可切）、玻璃卡片、HUD 取景框、蓝图网格背景、图表专用 token、`prefers-reduced-motion` |
| 应用壳 | 左侧图标导航（窄屏收起）+ 语言/主题/链路状态；全站**单条** WebSocket（替代 5 页各建一条 + 5 份重复常量） |
| Dashboard | Hero 设备卡（在线/固件/IP/运行时长）+ SVG 环形温度仪表 + 容差窗口电压条 + 8 路风扇阵列 + 告警横幅 |
| Fans | 环形仪表卡 + **拖动实时生效**（150ms 防抖）+ 模式乐观更新（3s 防回弹）+ 挡位预设（静音/标准/强劲/全速）+ AUTO 命中解释（温度源读数 → LUT 段 → 目标 duty） |
| 曲线编辑 | 每卡独立抽屉：**自绘 SVG 拖拽点**（严格递增 clamp、线段加点、双击删点、平滑预览）+ 温度源下拉 + PID 字段说明 + **曲线预设**（localStorage，JSON 导入导出）+ 回读回显 |
| Alerts | 接通 `config/alert get` 设备规则回读、severity 过滤、相对时间 |
| Devices | 链路状态卡（后端 + MQTT Broker，`/health` 新增 mqtt 字段）、OTA 进度、重启对话框 |
| History | 后端环形缓冲真数据（2s 采样、24h 上限、≤600 点降采样）：真实时间轴、风扇筛选、双语图例、CSV 导出（7d 选项按计划移除） |
| 拆包 | vite manualChunks：主包 600kB → 139kB（radix/recharts/i18n 独立 chunk） |

## 后端变更（零固件改动）

- `GET /api/devices/:id/curve/:fanIdx` — 曲线回读缓存（设备无回读协议，缓存最近下发命令）
- `GET /api/devices/:id/history` — stub → 环形缓冲真数据（`history.ts`，HISTORY_HOURS 可配，默认 24h）
- `GET /health` 增加 `mqtt` 字段；订阅 `config/#`（alert/curve 回读）；status 捕获 `uptime_seconds`

## 验证证据

| 检查 | 结果 |
|---|---|
| `tsc --noEmit` + `vite build`（frontend） | ✅ 通过 |
| `npm run build`（backend） | ✅ 通过 |
| 冒烟测试 `smoke_test.sh 192.168.3.131 localhost` | ✅ PASS: 25 / FAIL: 0 |
| 模拟器契约自检 `selftest.js` | ✅ PASS: 43 / FAIL: 0 |
| 端到端闭环 | ✅ 拖拽改点 → 下发 → MQTT → 模拟器回执 → F0 卡显示"当前 X°C · BME280 板载 → 目标 Y%"，duty 跟随 |
| 规则回读 | ✅ "读取设备规则" → toast 已读取，规则经 WS 应用 |
| 走查 | ✅ 6 视图 × zh/en × 暗/亮（截图见 redesign-evidence/） |

## 走查中发现并修复的问题

1. 气压单位错误（hPa 被再除以 100 显示 10.1 hPa）→ 修正为原值 hPa
2. `.hud{position:relative}` 定义在 utilities 之后覆盖对话框 `fixed` → 移入 `@layer components`
3. CUA 合成事件只含 mouse 时拖拽失效 → CurveCanvas 增加 mouse 事件兜底

## 走查中确认的环境现象（非缺陷）

- 契约自检首轮 3-5 项失败：演示模拟器与自检实例同用 `esp32-sim0001` 互发状态污染断言；停掉演示实例后 43/0
- IAB 浏览器在超高视口/fullPage 截图下的画面重影为截图合成残影（DOM 数量核验正常）

## 本轮不做（维持规划）

前端 WS 收口（F6：`ws://:3001` → nginx `/ws` + wss）、OTA 本地文件上传、告警持久化、固件侧曲线回读/共振避让/学习型控温。

**截图证据**：`redesign-evidence/`（6 张：暗色中文 Dashboard/Fans/曲线拖拽/Alerts/Devices + 亮色英文 Dashboard）

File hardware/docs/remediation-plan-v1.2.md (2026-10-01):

# 硬件整改清单 v1.2（Remediation Plan）

> 本文档是给整改执行 agent 的**唯一权威依据**（硬件部分）。执行时以本文档的引脚表和决策为准，
> 与旧文档（v1.1 指南、旧 BOM、组装指南）冲突时一律以本文档为准。
> 审查背景见 2026-08-23 的硬件审查结论（占位原理图/PCB、引脚冲突、ADC 引脚错误、扩展板供电矛盾等）。
> **v1.2.1（2026-08-24）**：吸收 `docs/module-review-report.md`（75 条发现）中与硬件相关的增量——
> H-03 扩展（分压比/console 路由/五处硬编码）、H-06/H-07 勘误（README 现状为 4 路而非 6 路；
> `hardware/BOM.csv` 实际存在）、新增 H-17（PWM 下拉）。
> 固件非引脚类问题与 agent/web/ha/test 的整改由 **`docs/module-remediation-plan-v1.2.md`** 承接。

---

## 0. 已确认的设计决策（不得偏离）

| # | 决策 | 说明 |
|---|---|---|
| D1 | **扩展板独立 SATA 供电** | 扩展板为用户自购成品板，自带 SATA 供电，接主控任意一路 4Pin 风扇座即原生可用。主控板**不做任何**为其供电的电路（删除 PH2.0 12V 供电、EXT_PWM、GPIO13 扩展板专用信号等所有相关设计）。固件也**不需要**为该路做特殊逻辑——它就是一个普通风扇通道。建议默认接 Fan6（J8）。 |
| D2 | **主控板风扇路数 = 8 路** | 依据：ESP32-S3 的 LEDC 恰好 8 通道、PCNT 恰好 4 单元×2 通道=8、2 片 74AHCT125 恰好 8 个缓冲通道，三个资源同时用满；超过 8 路需外加芯片，超出单板定位。总风扇数 = 7 独立 + 12 统一 = 19。 |
| D3 | **板卡规格：≤99×99mm，4 层板** | 嘉立创免费打样已确认（2026-08 核实）：2 层和 4 层板均免费，尺寸 ≤100×100mm，每次 5 片，每月 2 张免费券；需保持标准工艺（板厚 1.6mm、外层 1oz）。板框取 99×99mm 留公差余量。叠层：L1 信号+元件 / L2 完整 GND / L3 电源（12V 铺铜 + 5V/3.3V）/ L4 信号。 |
| D4 | **USB VBUS 与 SATA 5V 二极管或** | VBUS 经肖特基 D3（B5819W）接入 +5V 轨，与 SATA 5V 支路 D2 构成二极管或，杜绝倒灌。USB 单独供电时板卡可工作（调试场景），SATA 供电时 USB 仅作数据。 |
| D5 | **UART0（GPIO43/44）让渡给屏幕 SPI** | 控制台与烧录一律走 USB-CDC（GPIO19/20 原生 USB，S3 支持 ROM 下载模式），不设 UART 调试串口。 |
| D6 | **嘉立创 EDA 为唯一硬件真源；旧 KiCad 工程归档 legacy/** | v1.2 原理图/PCB 由用户在嘉立创 EDA（专业版）绘制，可编辑工程存 `hardware/lceda/`，导出物（原理图 PDF、BOM、Gerber、钻孔、ERC/DRC 证据）归档 `hardware/`。旧 KiCad 工程（占位 kicad_*、文本 .sch、旧 gerber）已于 2026-08-26 整体移入 `hardware/legacy/` 仅供参考，不再维护；**不参与任何 grep 验收**（命令统一加 `--exclude-dir=legacy`）；legacy 内 `.bak`/`.v?backup` 保持 git 不跟踪。 |

**禁用引脚背景（必须写进原理图注释）：**
- GPIO26~32：模组内 SPI Flash 占用，WROOM-1 未引出。
- GPIO35~37：N16R8 为八线 PSRAM 版本，GPIO35/36/37 被模组内 PSRAM 占用，**不可用**（现有原理图符号里画了这三个引脚，需标注 NC）。GPIO33/34 模组未引出。
- Strapping 引脚（GPIO0/3/45/46）：复位瞬间电平影响启动，除本表指定用法外禁止外接负载。

---

## 1. v1.2 GPIO 分配总表（唯一权威，全项目以此为准）

| GPIO | 网络名 | 方向 | 外设资源 | 备注 |
|:----:|---|:----:|---|---|
| EN | RESET | IN | — | 10kΩ 上拉 + 100nF 去抖 + SW1 接地 |
| GPIO0 | BOOT | IN | strapping | 10kΩ 上拉 + SW2 接地 |
| GPIO1 | ADC_12V | IN | ADC1_CH0 | 100k/20k 分压（÷6） |
| GPIO2 | ADC_5V | IN | ADC1_CH1 | 47k/10k 分压（÷5.7） |
| GPIO3 | **NC** | — | strapping | JTAG 源选择，禁止外接任何负载 |
| GPIO4 | ADC_3V3 | IN | ADC1_CH3 | 47k/10k 分压（÷5.7） |
| GPIO5 | FAN1_PWM | OUT | LEDC_CH0 | → 74AHCT125 #1 |
| GPIO6 | FAN2_PWM | OUT | LEDC_CH1 | → 74AHCT125 #1 |
| GPIO7 | FAN3_PWM | OUT | LEDC_CH2 | → 74AHCT125 #1 |
| GPIO8 | FAN4_PWM | OUT | LEDC_CH3 | → 74AHCT125 #1 |
| GPIO9 | FAN5_PWM | OUT | LEDC_CH4 | → 74AHCT125 #2 |
| GPIO10 | FAN6_PWM | OUT | LEDC_CH5 | → 74AHCT125 #2，**建议接扩展板** |
| GPIO11 | FAN7_PWM | OUT | LEDC_CH6 | → 74AHCT125 #2 |
| GPIO12 | FAN8_PWM | OUT | LEDC_CH7 | → 74AHCT125 #2 |
| GPIO13 | FAN1_TACH | IN | PCNT_U0_CH0 | 分压输入（见 §2 Tach 网络） |
| GPIO14 | FAN2_TACH | IN | PCNT_U0_CH1 | |
| GPIO15 | FAN3_TACH | IN | PCNT_U1_CH0 | |
| GPIO16 | DS18B20_DQ | I/O | OneWire | 4.7kΩ 上拉，J11/J12 两探头共用 |
| GPIO17 | I2C_SDA | I/O | I2C0_SDA | 4.7kΩ 上拉，BME280 + 屏幕 |
| GPIO18 | I2C_SCL | OUT | I2C0_SCL | 4.7kΩ 上拉 |
| GPIO19 | USB_D- | I/O | USB-Serial-JTAG | 原生 USB |
| GPIO20 | USB_D+ | I/O | USB-Serial-JTAG | 原生 USB |
| GPIO21 | FAN4_TACH | IN | PCNT_U1_CH1 | |
| GPIO38 | FAN5_TACH | IN | PCNT_U2_CH0 | |
| GPIO39 | FAN6_TACH | IN | PCNT_U2_CH1 | MTCK，正常 GPIO 使用 |
| GPIO40 | FAN7_TACH | IN | PCNT_U3_CH0 | |
| GPIO41 | FAN8_TACH | IN | PCNT_U3_CH1 | |
| GPIO42 | SPI_SCK | OUT | GPIO 矩阵 | 屏幕预留（J13 Pin3） |
| GPIO43 | SPI_MOSI | OUT | GPIO 矩阵 | 屏幕预留（原 UART0_TX，J13 Pin4） |
| GPIO44 | SPI_CS | OUT | GPIO 矩阵 | 屏幕预留（原 UART0_RX，J13 Pin5），**10kΩ 上拉到 3.3V**（防上电阶段 UART0 启动日志串入屏幕） |
| GPIO45 | WS2812B_DI | OUT | RMT | strapping(VDD_SPI 电压)：WS2812 DIN 为高阻输入，复位期内部下拉保持 VDD_SPI=3.3V，安全 |
| GPIO46 | **NC** | — | strapping | boot 模式选择，禁止外接任何负载 |
| GPIO47 | BTN_WIFI_CFG | IN | GPIO 输入 | 10kΩ 上拉 + SW3 接地 |
| GPIO48 | SPI_DC | OUT | GPIO 矩阵 | 屏幕预留（J13 Pin6） |

风扇索引约定：文档写 Fan1~Fan8，固件/协议用 index 0~7（Fan1=index 0）。

**接口位号 v1.2：** J1 SATA、J2 USB-C、J3~J10 八路风扇座、J11/J12 DS18B20 端子（XH2.54-3P）、J13 屏幕排针（2.54-8P）。不再有"扩展板专用接口"。

---

## 2. 电源架构 v1.2

```
SATA 12V (Pin13-15) → F1 [PTC, hold ≥3A] → D1 [SS34] → +12V 轨
    +12V 轨 → J3~J10 Pin2（8 路风扇，每路 100nF 去耦）
    +12V 轨 → 100k/20k 分压 → GPIO1

SATA 5V (Pin7-9) → F2 [PTC 1A] → D2 [B5819W] ──┐
USB-C VBUS       → D3 [B5819W] ────────────────┴→ +5V 轨
    +5V 轨 → AMS1117-3.3 → +3V3（10µF+100nF 输出，≥8×100nF ESP32 去耦）
    +5V 轨 → 74AHCT125 #1/#2 VCC（各 100nF 去耦）
    +5V 轨 → 8 路 Tach 上拉（10kΩ×8）
    +3V3 → ESP32 / BME280 / WS2812B / DS18B20 / 全部上拉与分压下臂
```

要点：
- F1 必须 hold ≥3A（8 风扇 ≈2.4~2.8A 稳态 + 启动浪涌；原 MF-MSMF250 的 2.5A hold 会误跳）。选型在 MF-SM 系列（1812/2920）或嘉立创基础库等效 ≥3A hold PTC。
- 12V 载流按 IPC-2150：1oz 外层 2mm 走线仅约 4A（10℃ 温升），**删除旧文档"2.0mm=6A"的错误表述**。4 层板中 12V 在 L3 铺铜（≥5mm 宽或区块铺铜），过孔阵列换层。
- SATA Pin1-3（3.3V/PWDIS）不连接，维持原设计。
- USB VBUS 支路可加可选 1A PTC（位号预留 F3，NC 亦可）。

## 3. 关键电路规范（与 v1.1 的差异已标注）

**Tach 输入网络（每路 3 电阻 + 1 电容，共 8 组）：**
```
风扇 Pin3(Tach, 开漏) ──[10kΩ 上拉至 +5V]──┬──[10kΩ 串联]──┬──→ GPIO
                                            │                │
                                          (节点)          [10kΩ 下拉至 GND] + [1nF 至 GND]
高电平 = 5V × 10k/(10k+10k) = 2.5V > VIH 2.31V ✓
```
共需：10kΩ×24 只（8 路上拉/串联/下拉各 8）+ 1nF×8。旧文档"10k×12"数量不足，一并修正。

**74AHCT125（2 片，SOIC-14）：**
- #1：4 通道全用（GPIO5~8 → FAN1~4_PWM）；#2：4 通道全用（GPIO9~12 → FAN5~8_PWM）。
- 两片的 OE1~OE4（Pin1/4/10/13）**全部接 GND** 并在原理图明确画出。
- 无悬空输入（旧文档"Pin9~12 悬空或接地"作废，本方案 8 通道全用，不存在未用通道）。
- VCC=+5V，各配 100nF 去耦。
- **每路 A 输入线（GPIO5~12 的 PWM 网络）加 10kΩ 下拉到 GND，共 8 只（H-17）**：上电窗口期
  ESP32 引脚为高阻、OE 又恒使能，不加下拉则缓冲输出电平不定、风扇可能满转数百毫秒
  （模块审查 MA-19 的硬件侧对策；固件侧对策见模块整改清单 FW-14——app_main 最早配置 LEDC duty=0）。

**USB-C（J2）+ ESD：**
- CC1/CC2 各 5.1kΩ 下拉；A6/A7 与 B6/B7 并联；VBUS 经 D3 进 +5V 轨（见 §2）。
- USBLC6-2SC6 的 VCC 接 **+5V 轨**（旧文档接 3.3V 有误：该器件按 5V 供电设计，3.3V 供电时对 D± 的钳位行为不正确）。
- D± 差分 90Ω、等长误差 ≤5mm、紧邻 J2 放置。

**BME280 / DS18B20 / WS2812B：** 与 v1.1 相同（I2C 0x76、SDO→GND、CSB→3.3V；OneWire GPIO16；WS2812 DIN 串 33~100Ω 抑制振铃，电源 100nF 去耦）。

**屏幕接口 J13（2.54 排针 8P）：**
Pin1=3.3V, Pin2=GND, Pin3=SPI_SCK(GPIO42), Pin4=SPI_MOSI(GPIO43), Pin5=SPI_CS(GPIO44, 带 10k 上拉), Pin6=SPI_DC(GPIO48), Pin7=I2C_SDA(GPIO17), Pin8=I2C_SCL(GPIO18)。

**ADC 分压网络：**
| 网络 | 上臂 | 下臂 | 分压比 | 12V→2.0V / 5V→0.88V / 3.3V→0.58V |
|---|---|---|---|---|
| ADC_12V | 100kΩ | 20kΩ | ÷6 | 全部 ≤2.0V，低于 ADC 安全区上限 |
| ADC_5V | 47kΩ | 10kΩ | ÷5.7 | 旧审查清单中"47k+18k"的矛盾表述删除 |
| ADC_3V3 | 47kΩ | 10kΩ | ÷5.7 | GPIO4（原 GPIO36 方案作废，GPIO36 不可用） |

---

## 4. 整改项清单

优先级：P0=阻断性（不做完不许进入下一项）；P1=设计缺陷；P2=改进建议。

### P0 项

**H-01 完整重绘原理图（嘉立创 EDA v1.2 工程，D6）**
- 动作：在嘉立创 EDA（专业版）新建 v1.2 工程（存 `hardware/lceda/`；旧 KiCad 占位工程已移入 `hardware/legacy/`，不得作为底稿），按本文档 §1~§3 绘制全部电路：电源（SATA/PTC/二极管或/LDO）、ESP32 最小系统（EN/BOOT 按键+上拉+去抖）、8 路 PWM、8 路 Tach 网络、BME280、DS18B20×2 端子、WS2812B、USB-C+USBLC6、屏幕排针 J13、3 路 ADC 分压、WiFi 按键、安装孔。
- 原理图符号修正：ESP32-S3 符号中 GPIO35/36/37 引脚标注 NC（N16R8 被 PSRAM 占用）；补全 GPIO26~32 缺失说明。
- 验收：ERC 0 错误 0 警告；每个网络连通完整；每片 IC 电源脚 100nF 去耦；所有元件有位号+数值+封装；导出的原理图 PDF 与可编辑工程归档；`grep -rni "placeholder" hardware/lceda/ hardware/*.pdf 2>/dev/null` 为空（legacy/ 不检查）。

**H-02 重绘 PCB（嘉立创 EDA v1.2 工程，D6）**
- 动作：板框 99×99mm；4 层叠层按 D3；按 v1.1 指南布局思路重排（SATA/USB-C 板边、ESP32 居中且**天线端出板边或天线区板外悬空**、15×15mm 天线禁布区用 EDA 的 keepout（禁布区）功能实现而非丝印文字、风扇座两行排列、L2 全 GND 平面）。
- 布线约束：12V 在 L3 铺铜；USB D± 差分 90Ω 等长 ≤5mm；AMS1117 散热焊盘 ≥4cm² GND 铺铜 + 2mm 间距过孔阵列；去耦电容距 IC 电源脚 <5mm。
- 工艺按嘉立创免费档：最小线宽/间距 0.127mm（设计目标 ≥0.2mm），过孔 0.3/0.6mm，1.6mm 板厚，1oz。
- 验收：DRC 0 错误；板框 ≤99×99mm；L2 无除过孔外的分割；4 个 M3 安装孔四角；keepout zone 存在于文件中。

**H-03 固件引脚同步（与 H-01 并行可做；v1.2.1 已按模块审查 MA-07/MA-21/MA-34 扩展）**

> 先决条件提示：模块审查判定固件当前存在 2 处编译错误（MA-01 `ESP_ERROR_CHECK(void)`、
> MA-02 main 组件 REQUIRES 缺失），由模块整改清单 Phase 0 的 FW-01/FW-02 修复。
> 本项的 grep 验收不依赖编译，但最终的 `idf.py build` 验收依赖两者都完成。

精确改动（含注释同步）：
```c
// firmware/components/fan_pwm/fan_pwm.h
#define FAN_PWM_COUNT 8            /* 原 4 */

// firmware/components/fan_pwm/fan_pwm.c
static const int FAN_GPIO[FAN_PWM_COUNT] = { 5, 6, 7, 8, 9, 10, 11, 12 };
/* 原 {4,5,6,7}；ESP32-S3 LEDC 共 8 通道，全部占用，共用 1 个 timer */

// firmware/components/fan_tach/fan_tach.h
#define FAN_TACH_COUNT 8           /* 原 4 */

// firmware/components/fan_tach/fan_tach.c
static const int TACH_GPIO[FAN_TACH_COUNT] = { 13, 14, 15, 21, 38, 39, 40, 41 };
/* 原 {8,9,10,11}；S3 仅 4 个 PCNT 单元×2 通道，unit = i/2, channel = i%2，
   需同步修改 PCNT 配置代码（原 4 路大概率 unit=i，会越界） */

// firmware/components/power_monitor/power_monitor.c
#define CH_12V  ADC_CHANNEL_0   /* GPIO1，原 CH_12V=CH2(GPIO3) */
#define CH_5V   ADC_CHANNEL_1   /* GPIO2 */
#define CH_3V3  ADC_CHANNEL_3   /* GPIO4，原 CH_3V3=CH0(GPIO1)；ADC1_CH3=GPIO4 */

// firmware/components/status_led/status_led.c
#define LED_GPIO 45             /* 原 48 */

// firmware/components/wifi_manager/wifi_manager.c
#define BTN_GPIO 47             /* 原 38，与 FAN5_TACH 冲突 */

// ---------- v1.2.1 增量（模块审查发现，原 H-03 未覆盖）----------

// firmware/components/power_monitor/power_monitor.h  —— MA-21
#define VOLTAGE_DIVIDER_5V  5.7f   /* 原 2.0f；硬件 47k/10k=÷5.7，不改则读数偏差 2.85 倍 */
#define VOLTAGE_DIVIDER_3V3 5.7f   /* 原 2.0f；同上 */
/* 12V 常数核对为 6.0f（100k/20k=÷6）；头文件中的分压网络描述注释同步更新 */

// firmware/sdkconfig.defaults  —— MA-34
/* 控制台与日志路由改走 USB-Serial-JTAG（GPIO19/20），不得再走 UART0：
   GPIO43/44 已让渡给屏幕 SPI（决策 D5），日志继续走 UART0 会与屏幕信号冲突。
   增加 CONFIG_ESP_CONSOLE_USB_SERIAL_JTAG=y 作为默认控制台 */

// 路数硬编码清理（MA-07 连带，共五处；索引仍为 0 基）：
//   fan_curve.h:10          FAN_CURVE_FANS 4   → 8
//   flash_storage.h:17      fan_rpm[4]         → fan_rpm[8]
//   main.c:280,301          循环字面量 4       → 引用各组件 COUNT 宏
//   alert_manager.c:35,87,113 数组与循环 4      → 8（或本组件宏）
```

- 验收（在仓库根执行，全部必须为空或符合注释）：
```bash
grep -rn "{ 4, 5, 6, 7 }" firmware/                      # 空
grep -rn "FAN_PWM_COUNT 4\|FAN_TACH_COUNT 4" firmware/   # 空
grep -n "LED_GPIO         48" firmware/components/status_led/status_led.c   # 空
grep -n "BTN_GPIO        38" firmware/components/wifi_manager/wifi_manager.c # 空
grep -rn "ADC_CHANNEL_2" firmware/components/power_monitor/  # 空（12V 不再在 GPIO3）
grep -n "VOLTAGE_DIVIDER" firmware/components/power_monitor/power_monitor.h  # 5V/3V3=5.7f，12V=6.0f
grep -n "CONSOLE_UART" firmware/sdkconfig.defaults                          # 空
grep -rn "FAN_CURVE_FANS 4\|fan_rpm\[4\]" firmware/                          # 空
```
- 连带检查：`fan_pwm.c` 的日志字符串（如 "GPIO4-7"）同步改为 "GPIO5-12"；`fan_tach.c` 的 "GPIO8-11" 同理。
- 协议层与 web/HA 的风扇数量扩散影响（15 处口径，见审查报告表 2）由模块整改清单 WEB-03/HA-02 等项承接，不在本项范围。

**H-04 扩展板矛盾清理（文档层）**
- 动作：在 `hardware/docs/hardware-design-guide-v1.1.md`（升级为 v1.2）与 `hardware/docs/schematic-review-checklist.md` 中：删除"J11 PH2.0-3P 扩展板 12V 供电"、删除"GPIO13 → 74AHCT125 → 扩展板 PWM"、删除"扩展板优先级最高/最低转速阈值/独立控制曲线"等特殊固件逻辑章节；统一表述为 D1 的口径（扩展板=接在一路风扇座上的普通风扇，独立 SATA 供电，推荐 J8）。
- 验收（v1.2.2 修正：原命令会命中本计划自身；且 GPIO13 已是合法的 FAN1_TACH 引脚，不能要求全库为空）：
```bash
grep -rn "EXT_PWM" hardware/docs/ --exclude=remediation-plan-v1.2.md --exclude=changelog-v1.2.md   # 空（两份元文档不参与扫描）
grep -rn "GPIO13" hardware/docs/ --exclude=remediation-plan-v1.2.md --exclude=changelog-v1.2.md | grep -v "FAN1_TACH"   # 空
grep -rn "扩展板" hardware/docs/ --exclude=remediation-plan-v1.2.md | grep "12V\|供电\|PWM"   # 仅剩 D1 口径表述（扩展板=普通风扇位，独立供电）
```
外加人工确认：文档中不存在任何"主控板给扩展板供 12V"的表述。

**H-05 USB/SATA 倒灌防护**
- 动作：按 §2 增加 D3（B5819W，VBUS→+5V 轨）；原理图中 USB VBUS 不得与 SATA 5V 有任何直连路径。
- 验收：原理图网络检查：VBUS 网络仅连接 J2、USBLC6（若接 VBUS 版）、D3 阳极；无直连 +5V/SATA 节点。

**H-06 BOM v1.2 重做（`hardware/docs/bom-main-board-v1.1.md` → 新文件 `bom-main-board-v1.2.md`）**
- 动作：按 §1~§3 重列：风扇座×8、74AHCT125×2、Tach 电阻 10kΩ×24 + 1nF×8、D3 新增、F1 ≥3A 选型、10µF 电容耐压改 16V/25V、屏幕排针 J13 位号、PWM 下拉 10kΩ×8（H-17）；删除 J11 PH2.0 行。逐位号与原理图核对。
- **`hardware/BOM.csv` 实际存在（模块审查 MF-09 勘误：此前误判为缺失），但内容是 v1.1 旧口径**——将其同步重写为 v1.2 内容（位号/规格/数量与新 md BOM 完全一致，供嘉立创 BOM 配单上传使用）。
- 验收：BOM 位号集合 == 原理图位号集合（写一个对照表附在 BOM 末尾）；无 18kΩ 规格（已废除）；F1 规格含 "3A" 及以上 hold；`hardware/BOM.csv` 与 md BOM 的位号/数量逐行一致。

**H-07 全部文档同步**
- `hardware/docs/hardware-design-guide-v1.1.md` → v1.2：引脚表、路数、板尺寸 99×99/4 层、电源架构、走线载流表述全部替换；删除"扩展板 v1.0 BOM"章节（扩展板为成品，改为一句话说明 D1）。
- `docs/hardware-assembly.md`：按 v1.2 重写（8 路、新位号、删除不存在的 D3 SRV05-4/D4~D8 TVS 表述）。注意：`hardware/BOM.csv` **实际存在**（v1.1 旧口径，MF-09 勘误），由 H-06 同步重写为 v1.2 后，组装指南同时引用 md 与 csv 两个 BOM。
- `hardware/docs/schematic-review-checklist.md`：引脚表与 §1 对齐（ADC 引脚、GPIO47 按键、GPIO45 WS2812、GPIO44 CS 上拉）；第 8 节扩展板检查表改为 D1 口径。
- `README.md` 硬件章节：现状为 **4 路**（模块审查 MF-01 勘误，并非此前误记的 6 路）→ 统一改为 8 路；尺寸/层数更新为 99×99mm 4 层；总风扇数 7 独立 + 12 统一 = 19。`docs/index.html`（GitHub Pages 门面）同口径修正（MF-02，由模块整改清单 DOC-03 承接）。
- v1.1 旧文档处置：`hardware-design-guide-v1.1.md` 与 `bom-main-board-v1.1.md` 升级替换为 v1.2 后**删除旧文件或移入 `hardware/legacy/`**（二者择一并在硬件 changelog 登记），否则下方 grep 无法清零。
- 验收（v1.2.2 修正：原命令会命中本计划自身与审查档案；legacy/ 归档不检查）：
```bash
grep -rn "100×70\|100x70" hardware/ docs/ README.md   --exclude-dir=legacy --exclude=remediation-plan-v1.2.md --exclude=changelog-v1.2.md   # 空
grep -rn "GPIO21.*ADC\|GPIO35.*ADC\|GPIO36.*ADC\|ADC.*GPIO21\|ADC.*GPIO35\|ADC.*GPIO36" hardware/ docs/   --exclude-dir=legacy --exclude=remediation-plan-v1.2.md --exclude=changelog-v1.2.md   --exclude=module-review-plan.md --exclude=module-review-report.md   # 空（审查档案与元文档不改写）
grep -rn "6 路\|6路" hardware/docs/ README.md   --exclude=remediation-plan-v1.2.md --exclude=changelog-v1.2.md   --exclude=module-review-plan.md --exclude=module-review-report.md   # 空
```
外加人工确认：所有文档路数表述为 8。

### P1 项

**H-08 USBLC6 VCC 改接 +5V 轨**（随 H-01 落实，单独列为验收点：原理图 U5 Pin5 网络 = +5V）。

**H-09 74AHCT125 使能与去耦完整**（随 H-01 落实，验收点：两片共 8 个 OE 脚全部接 GND、两个 VCC 各 100nF）。

**H-10 F1 选型与 12V 载流**（随 H-02/H-06 落实，验收点：BOM 中 F1 hold ≥3A；PCB 12V 为 L3 铺铜且旧"2mm=6A"表述已在文档删除）。

**H-11 Tach 网络补齐**（随 H-01/H-06 落实，验收点：原理图每路 3 电阻 + 1nF，共 8 路；BOM 数量 24+8）。

**H-12 SPI_CS 上拉与 strapping 标注**（随 H-01 落实，验收点：GPIO44 有 10k 上拉到 3.3V；GPIO3/GPIO46 在原理图标 NC）。

**H-17 PWM 输入线下拉电阻（新增于 v1.2.1，源自模块审查 MA-19）**
- 动作：8 路 PWM 网络（GPIO5~12 → 74AHCT125 的 A 输入）各加 10kΩ 下拉到 GND（见 §3 74AHCT125 节说明）。
- 验收：原理图 8 个 PWM 网络各有下拉电阻；BOM 含 10kΩ 增量×8（随 H-01/H-06 落实）。
- 配套（不在本清单）：固件侧 app_main 最早配置 LEDC duty=0，见模块整改清单 FW-14。

### P2 项

**H-13 AMS1117 热设计**：散热焊盘 ≥4cm² GND 铺铜 + 过孔阵列；文档注明"若 WiFi 高负载下 3.3V 跌落 >5%，备选 AZ1117-3.3（SOT-223 引脚兼容）"。

**H-14 WS2812 数据线串 33~100Ω**（抑制振铃，随 H-01 落实，BOM 加 1 只 0805 电阻）。

**H-15 仓库清理（v1.2.2 调整：配合 D6，备份不再删除而是归档）**：旧 KiCad 工程已整体移入 `hardware/legacy/`（2026-08-26 执行完毕）；`.gitignore` 已含 `*.bak`、`*.v7backup`（模块整改 DOC-05 顺带完成）。验收：`git ls-files hardware/legacy/ | grep -E "bak|v7backup"` 为空（legacy 内备份文件磁盘保留、git 不跟踪）。

**H-16 清理文档死链接**：`hardware/docs/hardware-design-guide-v1.1.md` 附录引用的 `bom-*.xlsx`、`pcb-layout-example.png`、`test-procedure.md` 均不存在，删除或替换为实际存在的仓库内文件。

---

## 5. 总验收门（整改完成的定义）

1. `hardware/lceda/` 嘉立创 EDA 工程（D6）：ERC=0、DRC=0、无 placeholder 内容；仓库内无被 git 跟踪的 .bak/.v7backup 文件（legacy/ 归档不参与验收）。
2. 三方一致性：本文档 §1 引脚表 == 原理图网络 == 固件 define（H-03 的 grep 全部通过）。
3. BOM ↔ 原理图 1:1（H-06 的对照表存在且无差异行；`hardware/BOM.csv` 与 md 口径一致）。
4. 文档一致性：H-07 的 grep 全部通过；全仓库无 "GPIO21/35/36 作 ADC"、"主控给扩展板供电"、"6 路风扇"、"100×70mm"、"README 中 4 路口径" 的残留表述。
5. 产出一份 `hardware/docs/changelog-v1.2.md`，逐项勾选 H-01~H-17 的完成状态与验证证据（命令+输出摘录）。
6. 固件构建：`idf.py build` 通过 —— **已于 2026-08-25 实测完成**（ESP-IDF v5.3.5，bin 0x11EA90 / 分区余 25%，证据见 `docs/changelog-modules-v1.2.md` §8）。

## 6. 明确不做的事

- 不为扩展板做任何供电/兼容电路或专用固件逻辑（D1）。
- 不做超过 8 路的风扇扩展（D2 的资源边界）。
- 固件非引脚类问题（编译错误、MQTT/OTA/告警逻辑等）及 agent/web/ha/test/docs 的整改，全部由 `docs/module-remediation-plan-v1.2.md` 承接（依据 `docs/module-review-report.md` 的 75 条发现，2026-08-24）。本清单保留的固件改动仅 H-03 一项（引脚同步）。

---

**版本：** v1.2.2（2026-08-26）

**修订记录：**
- v1.2.2（2026-08-26）：新增决策 D6（嘉立创 EDA 为唯一硬件真源，旧 KiCad 工程移入 `hardware/legacy/` 归档，不参与 grep 验收）；H-01/H-02 目标改为嘉立创 EDA 工程；H-04/H-07 验收命令修正自噬缺陷（原命令命中本计划自身，且 GPIO13 已是合法 FAN1_TACH、"GPIO35/36 作 ADC"字样存在于审查档案中，均无法清零——现统一排除计划自身、审查档案与 legacy/）；H-07 明确 v1.1 旧文档需删除或归档；H-15 从"删除备份"改为"legacy 归档 + git 不跟踪"；§5-6 固件构建标注已实测通过；同日补充：验收命令统一排除 changelog-v1.2.md（销号日志与计划同为元文档，其中引用的旧字符串/验收命令原文不参与扫描）。
- v1.2.1（2026-08-24）：吸收模块审查报告（`docs/module-review-report.md`）增量——H-03 扩展（分压比 ÷5.7、console 路由 USB-CDC、五处路数硬编码、构建先决条件）；H-06/H-07 勘误（README 现状为 4 路而非 6 路；`hardware/BOM.csv` 实际存在需同步重写）；新增 H-17（PWM 下拉电阻，源自 MA-19）；§6 范围交接给模块整改清单。
- v1.2（2026-08-23）：初版。

**上游依据：** 2026-08-23 硬件审查报告；2026-08-24 模块审查报告（75 条发现）；嘉立创免费打样规则（2026-08 核实：[规则变更公告](https://www.jlc.com/portal/q7i59056.html)、[免费打样文档](https://wiki.lceda.cn/zh-hans/design-production/free-pcb.html)）

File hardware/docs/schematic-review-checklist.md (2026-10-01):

# 原理图审查清单 v1.2 (Schematic Review Checklist)

> 适用：嘉立创 EDA v1.2 工程（`hardware/lceda/`，决策 D6）。
> 引脚/电路标准以 `remediation-plan-v1.2.md`（v1.2.2）§1~§3 为唯一权威；
> 本清单与 v1.1 的主要差异：8 路风扇、ADC 引脚 GPIO1/2/4、WS2812 GPIO45、按键 GPIO47、
> PWM 下拉×8、USBLC6 VCC=+5V、F1 ≥3A、扩展板改为 D1 口径（无专用电路）。

## 使用说明

在提交 PCB 布局前，按此清单逐项检查原理图，避免返工。

**检查流程：**
1. 打印原理图 PDF（或双屏对照）
2. 逐项勾选 `[ ]` → `[x]`
3. 发现问题记录在"备注"列
4. 全部通过后方可进入 PCB 设计

---

## ✅ 1. 电源系统检查

| 检查项 | 状态 | 标准 | 备注 |
|---|:----:|---|---|
| SATA接口Pin7-9接5V | [ ] | Pin7/8/9并联 | |
| SATA接口Pin13-15接12V | [ ] | Pin13/14/15并联 | |
| SATA所有GND引脚连接 | [ ] | Pin4/5/6/10/11/12 | |
| SATA Pin1-3不连接 | [ ] | PWDIS/3.3V，NC | |
| F1 位置与选型 | [ ] | 12V支路，**hold ≥3A**（MF-MSMF300-2 或等效） | 2.5A 会误跳 |
| F2 位置与选型 | [ ] | 5V支路，1A | |
| D1（SS34）12V 防反接 | [ ] | 阳极接SATA侧 | |
| **D2/D3 二极管或** | [ ] | SATA 5V→D2、USB VBUS→D3（均 B5819W）汇入 +5V 轨 | H-05：无直连倒灌路径 |
| F3（可选 PTC 1A） | [ ] | VBUS 支路，位号预留 NC 亦可 | |
| AMS1117输入端滤波电容 | [ ] | 470µF电解+100nF陶瓷 | |
| AMS1117输出端滤波电容 | [ ] | 10µF+100nF | |
| AMS1117散热焊盘连接GND | [ ] | Tab引脚标注GND | |
| 3.3V输出去耦电容数量 | [ ] | ≥8个100nF分布ESP32周围 | |
| 电源网络标签正确 | [ ] | +12V / +5V / +3V3 / GND | |

---

## ✅ 2. ESP32-S3核心电路

| 检查项 | 状态 | 标准 | 备注 |
|---|:----:|---|---|
| ESP32 VDD引脚接3.3V | [ ] | 全部VDD/VDDIO | |
| ESP32 GND引脚全连 | [ ] | 全部GND/EP | |
| EN引脚上拉10k | [ ] | 到3.3V + 100nF去抖 + RST按键 | |
| GPIO0上拉10k + BOOT按键 | [ ] | 到3.3V | strapping |
| **GPIO3/GPIO46 标注 NC** | [ ] | strapping，禁止外接负载 | |
| **GPIO35/36/37 标注 NC** | [ ] | N16R8 八线 PSRAM 占用，原理图符号上注明 | |
| GPIO26~32 未使用说明 | [ ] | 模组内 Flash，WROOM-1 未引出 | 原理图注释 |
| USB D+/D-连接正确 | [ ] | GPIO19→D-，GPIO20→D+ | |
| USB差分对ESD保护 | [ ] | USBLC6-2SC6，**Pin5 VCC 接 +5V 轨** | H-08：勿接 3.3V |
| 天线区域禁布区 | [ ] | 15×15mm keepout，天线端出板边/悬空 | |
| 所有已用GPIO有定义 | [ ] | 对照 §1 权威表，NC 除外 | |
| 电源引脚去耦电容 | [ ] | VDD附近100nF | |

---

## ✅ 3. 风扇控制电路（8 路）

### PWM 通道

| 检查项 | 状态 | 标准 | 备注 |
|---|:----:|---|---|
| GPIO5~12 → 74AHCT125 输入 A | [ ] | 8 路PWM（#1: GPIO5-8，#2: GPIO9-12） | |
| 74AHCT125 #1 VCC/GND | [ ] | Pin14=+5V / Pin7=GND | |
| 74AHCT125 #2 VCC/GND | [ ] | 同上 | |
| **两片共 8 个 OE 脚全接 GND** | [ ] | #1/#2 的 Pin1/4/10/13 | H-09：8个全部画 |
| 每个 VCC 去耦电容 | [ ] | 100nF ×2 | |
| **每路 PWM 线下拉 10kΩ 到 GND** | [ ] | GPIO5~12 共 8 只 | H-17：上电防满转 |
| 74AHCT125 输出 Y → 风扇座 Pin4 | [ ] | 5V PWM 信号 | |

### Tach 通道

| 检查项 | 状态 | 标准 | 备注 |
|---|:----:|---|---|
| Tach 引脚分配 | [ ] | GPIO13(FAN1_TACH)/14/15/21/38/39/40/41（PCNT 4单元×2通道） | unit=i/2, ch=i%2 |
| 每路 Tach 上拉到 5V | [ ] | 10kΩ ×8 | 开漏输出 |
| 每路 串联 10kΩ + 下拉 10kΩ + 1nF | [ ] | 3电阻+1电容 ×8（共 10k×24 + 1nF×8） | 分压后 2.5V > VIH 2.31V |
| 风扇 12V 引脚去耦电容 | [ ] | 每路 100nF ×8 | |
| 风扇座 Pin1 接地 | [ ] | J3~J10 全部 | |

---

## ✅ 4. 传感器接口

### BME280 (I2C)

| 检查项 | 状态 | 标准 | 备注 |
|---|:----:|---|---|
| SDA连接GPIO17 | [ ] | I2C0_SDA | |
| SCL连接GPIO18 | [ ] | I2C0_SCL | |
| SDA/SCL上拉电阻 | [ ] | 4.7kΩ到3.3V | |
| SDO引脚接GND | [ ] | I2C地址0x76 | |
| CSB引脚接3.3V | [ ] | I2C模式 | |
| VDD/VDDIO接3.3V | [ ] | 双电源引脚 | |
| GND接地 + 100nF去耦 | [ ] | | |

### DS18B20 (OneWire)

| 检查项 | 状态 | 标准 | 备注 |
|---|:----:|---|---|
| DQ连接GPIO16 | [ ] | OneWire数据 | |
| DQ上拉电阻 | [ ] | 4.7kΩ到3.3V | |
| 端子位号 J11/J12 | [ ] | XH2.54-3P，Pin1=GND/Pin2=DQ/Pin3=3.3V | |
| 两个端子并联到同一DQ | [ ] | 共用总线 | |
| 固件口径注记 | [ ] | 不支持寄生供电（外部供电设计） | |

### WS2812B (RGB LED)

| 检查项 | 状态 | 标准 | 备注 |
|---|:----:|---|---|
| DIN连接**GPIO45** | [ ] | RMT | v1.2：GPIO45，非 48 |
| DIN 串联 33~100Ω | [ ] | 抑制振铃 | H-14 |
| VDD接3.3V + 100nF去耦 | [ ] | Pin1 | |
| GND接地（Pin3），DOUT悬空 | [ ] | Pin2 NC | |
| strapping 安全性注记 | [ ] | GPIO45=VDD_SPI strapping，DIN 高阻+内部下拉，安全 | |

---

## ✅ 5. USB-C接口

| 检查项 | 状态 | 标准 | 备注 |
|---|:----:|---|---|
| A1/A12/B1/B12(GND)连接 | [ ] | 4个GND | |
| A4/A9/B4/B9(VBUS)并联 | [ ] | → D3 → +5V 轨 | 经二极管或，无直连 |
| CC1下拉5.1kΩ | [ ] | A5→GND | |
| CC2下拉5.1kΩ | [ ] | B5→GND | |
| A6/A7(D+/D-)连接 | [ ] | USB2.0 | |
| B6/B7(D+/D-)与A6/A7并联 | [ ] | | |
| USBLC6位置 | [ ] | 紧邻USB座 | |
| USBLC6接线 | [ ] | Pin1/3←USB, Pin4/6→ESP32, **Pin5 VCC=+5V** | H-08 |
| VBUS滤波电容 | [ ] | 10µF+100nF | |

---

## ✅ 6. ADC电压监控

### 12V监控（GPIO1 / ADC1_CH0）

| 检查项 | 状态 | 标准 | 备注 |
|---|:----:|---|---|
| 分压比 ÷6 | [ ] | 100kΩ + 20kΩ | |
| 上臂100kΩ连接12V | [ ] | | |
| 下臂20kΩ连接GND | [ ] | | |
| 分压点连接**GPIO1** | [ ] | ADC1_CH0 | |
| ADC输入≤2.0V | [ ] | 12V×1/6=2.0V | |

### 5V监控（GPIO2 / ADC1_CH1）

| 检查项 | 状态 | 标准 | 备注 |
|---|:----:|---|---|
| 分压比 ÷5.7 | [ ] | 47kΩ + 10kΩ | |
| 分压点连接**GPIO2** | [ ] | ADC1_CH1 | |

### 3.3V监控（GPIO4 / ADC1_CH3）

| 检查项 | 状态 | 标准 | 备注 |
|---|:----:|---|---|
| 分压比 ÷5.7 | [ ] | 47kΩ + 10kΩ | 旧"47k+18k"表述已废除 |
| 分压点连接**GPIO4** | [ ] | ADC1_CH3 | |

---

## ✅ 7. 屏幕接口（J13，2.54 排针 8P）

| 检查项 | 状态 | 标准 | 备注 |
|---|:----:|---|---|
| Pin1连接3.3V / Pin2连接GND | [ ] | 供电/地 | |
| Pin3连接GPIO42 | [ ] | SPI_SCK | |
| Pin4连接GPIO43 | [ ] | SPI_MOSI（原 UART0_TX） | |
| Pin5连接GPIO44 | [ ] | SPI_CS，**10kΩ 上拉到 3.3V** | H-12：防上电 UART0 日志串入 |
| Pin6连接GPIO48 | [ ] | SPI_DC | |
| Pin7/Pin8连接GPIO17/18 | [ ] | I2C（共用BME280） | |
| UART0 不再作 console 的注记 | [ ] | GPIO43/44 让渡（决策 D5） | |

---

## ✅ 8. 扩展板接入（D1 口径）

| 检查项 | 状态 | 标准 | 备注 |
|---|:----:|---|---|
| 无扩展板专用电路 | [ ] | 无专用供电/PWM 信号/接口 | D1：成品板独立 SATA 供电 |
| 扩展板接入方式说明 | [ ] | 接任意一路 4Pin 风扇座（建议 Fan8/J10），即普通风扇通道 | |

---

## ✅ 9. 通用原理图规范

| 检查项 | 状态 | 标准 | 备注 |
|---|:----:|---|---|
| 所有元件有唯一位号 | [ ] | R1, C1, U1... | |
| 所有元件有数值标注 | [ ] | 10kΩ, 100nF... | |
| 所有元件有封装信息 | [ ] | 0805, SOT-223... | |
| 电源/地使用符号 | [ ] | 不用长线连接 | |
| 网络标签命名清晰 | [ ] | 大写+下划线 | |
| 重要信号有注释 | [ ] | PWM频率、电压等级、禁用引脚 | |
| 无悬空输入引脚 | [ ] | 所有输入有确定电平 | |
| 无短接电源 | [ ] | VCC不直接接GND | |
| 原理图分页合理 | [ ] | 按功能模块分页 | |
| 版本号和日期标注 | [ ] | 标题栏 v1.2 | |

---

## ✅ 10. ERC检查结果

| 检查项 | 状态 | 标准 | 备注 |
|---|:----:|---|---|
| 运行ERC检查 | [ ] | 立创EDA"电气规则检查" | |
| 无未连接引脚警告 | [ ] | 0个警告 | |
| 无电源冲突 | [ ] | 无VCC短路到GND | |
| 无浮空输入 | [ ] | 所有输入有驱动源 | |
| 无多驱动冲突 | [ ] | 1个输出→N个输入 | |
| ERC错误数 = 0 | [ ] | 必须清零 | |

---

## ✅ 11. 对照BOM检查

| 检查项 | 状态 | 标准 | 备注 |
|---|:----:|---|---|
| 元件数量与BOM一致 | [ ] | 逐项核对（bom-main-board-v1.2.md，H-06 生成后） | |
| LCSC编号已标注 | [ ] | 元件属性字段 | |
| 封装与BOM一致 | [ ] | 0805/SOT-223等 | |
| 无停产元件 | [ ] | 嘉立创商城可购买 | |
| 价格在预算内 | [ ] | 单板≤30元 | |

---

## 审查签字

| 角色 | 姓名 | 日期 | 签字 |
|---|---|---|---|
| **原理图设计** | | | |
| **审查人** | | | |
| **批准人** | | | |

---

## 常见错误速查

### ❌ 致命错误（必须修复）

1. **电源短路** — VCC直接连GND
2. **极性反接** — 二极管/电解电容/LED方向错误
3. **ADC超压** — 分压后电压>2.45V
4. **USB D+/D-接反** — GPIO19/20错位
5. **I2C无上拉** — SDA/SCL浮空
6. **EN引脚无上拉** — ESP32无法启动
7. **Tach上拉到3.3V** — 风扇开漏输出无信号（必须拉5V）
8. **PWM无下拉** — 上电窗口风扇可能满转（H-17）
9. **USBLC6 VCC接3.3V** — 钳位行为不正确（必须 +5V，H-08）
10. **GPIO35/36/37 接了外设** — N16R8 被 PSRAM 占用，不可用

### ⚠️ 警告（影响性能）

1. **去耦电容不足** — 稳定性差
2. **PWM输出3.3V直连风扇** — 电平不足（必须经 74AHCT125）
3. **12V 走线依赖表层** — 1oz 2mm 仅约 4A@10℃，12V 应走 L3 铺铜
4. **USB差分线不等长** — 信号质量差
5. **GPIO44 无上拉** — 上电阶段 UART0 启动日志串入屏幕

---

**版本：** v1.2
**适用项目：** Smart Fan Controller Main Board（嘉立创 EDA v1.2 工程）
**更新日期：** 2026-08-26（依据 remediation-plan-v1.2.md v1.2.2 / H-04+H-07）

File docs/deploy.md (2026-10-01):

# 部署指南 — Smart Fan Controller

## 系统架构

```
ESP32-S3 (固件)
     │ SATA 12V/5V
     │ USB-CDC ←→ Go Agent (Linux) ←→ MQTT Broker ←→ Web APP
     │ WiFi ────────────────────────────────────────────┘
```

---

## 前置条件

| 工具 | 版本 | 安装 |
|---|---|---|
| ESP-IDF | v5.3+ | `./install.sh` [官方文档](https://docs.espressif.com/projects/esp-idf/zh_CN/latest/esp32s3/get-started/) |
| Go | 1.25+ | 官网安装包；Ubuntu 24.04 `apt install golang-go` 仅 1.22，依赖 `GOTOOLCHAIN=auto` 联网下载 1.25 工具链——离线/内网环境必须手动装 1.25+ |
| Node.js | 20+ | `curl -fsSL https://deb.nodesource.com/setup_20.x | sudo bash -` |
| Mosquitto | 2.0+ | `sudo apt install mosquitto mosquitto-clients` |
| git / curl | 任意 | `sudo apt install git curl`（克隆仓库与冒烟测试依赖） |

> 本文档假设仓库克隆至 `/opt/smart-fan/smart-fans-system`（§4.3 nginx 路径以此为准）。
> 国内拉取 Go 依赖建议：`go env -w GOPROXY=https://goproxy.cn,direct`。

---

## 第一步：固件烧录

### 1.1 编译固件

```bash
cd firmware
idf.py set-target esp32s3
idf.py build
```

预期输出: `Project build complete. Sending binaries to /build/`

### 1.2 首次烧录（完整擦除）

```bash
# 连接 Type-C USB 到电脑，按住 BOOT 键再插入
idf.py -p /dev/ttyACM0 flash monitor

# Windows 用户:
idf.py -p COM3 flash monitor
```

### 1.3 首次 WiFi 配网

1. 长按配网键（GPIO38）3秒，RGB LED 变为蓝色慢闪
2. 手机/电脑连接 WiFi 热点 `FanCtrl-XXXXXX`
3. 浏览器访问 `http://192.168.4.1`
4. 输入家庭 WiFi SSID 和密码，点击保存
5. 设备重启后自动连接 WiFi，LED 变为绿色呼吸

### 1.4 USB-CDC 串口调试

设备连接后可直接用串口终端（115200 波特率）发送命令：

```bash
# Linux/macOS
screen /dev/ttyACM0 115200

# 可用命令（与固件 FW-22 实现一致）
status            → 查看系统状态 JSON
fan <0-7> <0-100> → 设置风扇转速（如 fan 0 75 = 风扇0转速 75%，并切 MANUAL 模式）
wifi status       → 查看 WiFi 连接状态
wifi reset        → 恢复出厂（清除 WiFi/曲线/MQTT 配置后重启）
mqtt status       → 查看 MQTT broker 配置与连接状态
mqtt set <url>    → 设置 broker（如 mqtt set mqtt://192.168.1.100:1883，重启生效）
ota https://...   → 触发 OTA 更新
reboot            → 重启设备
help              → 命令列表

# 恢复某路风扇自动模式：发送曲线命令（REST/mosquitto）后设备回 auto，
# 或重启设备（曲线模式默认 LUT 自动）。
```

---

## 第二步：MQTT Broker 配置

```bash
# 启动 Mosquitto（允许匿名连接，局域网使用）
cat > /etc/mosquitto/conf.d/fan-ctrl.conf << 'EOF'
listener 1883
allow_anonymous true
EOF

sudo systemctl restart mosquitto
sudo systemctl enable mosquitto

# 验证连接（订阅端应打印: fan-controller/verify hello）
mosquitto_sub -h localhost -t "fan-controller/+" -v &
mosquitto_pub -h localhost -t "fan-controller/verify" -m "hello"
```

---

## 第三步：Go Agent 部署（Linux 服务器）

```bash
cd agent

# 1. 编译
make build

# 2. 编辑配置
sudo mkdir -p /etc/smart-fan-agent
cat > /etc/smart-fan-agent/config.yaml << 'EOF'
mqtt:
  broker: "mqtt://localhost:1883"   # 端口并入 URL（无独立 port 字段）
  client_id: "smart-fan-agent"
  topic_prefix: "fan-controller"
  username: ""                      # broker 启用鉴权时填写
  password: ""

serial:
  port: "/dev/ttyACM0"    # ESP32 USB-CDC 串口
  baud_rate: 115200

monitor:
  interval: 5             # 采集间隔(秒)
  gpu_enabled: true       # 有 NVIDIA GPU 才设为 true
EOF

# 3. 安装
sudo bash install.sh

# 4. 启动服务
sudo systemctl start smart-fan-agent
sudo systemctl status smart-fan-agent

# 5. 查看日志
journalctl -u smart-fan-agent -f
```

> **数据流说明**：Agent 采集的本机 CPU/内存/GPU 指标发布到
> `system-monitor/{hostname}/sensor/{system|gpu}`，**不会**出现在 Web 控制台
> （后端只订阅 `fan-controller/#`，控制台面向 ESP32 设备）。Agent 指标供 MQTT
> 订阅方（如 Home Assistant）消费；`/api/devices` 里看不到 agent 主机属正常现象。

---

## 第四步：Web 控制台部署

### 4.1 后端启动

```bash
cd web/backend
npm ci                # lockfile 已提交，用 ci 保证可复现
export MQTT_BROKER="mqtt://localhost:1883"
export PORT=3001
npm run build
npm start             # 前台运行；生产常驻建议 pm2 或 systemd 单元
```

### 4.2 前端构建

```bash
cd web/frontend
npm ci
npm run build
# 生成 dist/ 目录
```

### 4.3 Nginx 反向代理（可选，生产部署）

```nginx
server {
    listen 80;
    root /opt/smart-fan/smart-fans-system/web/frontend/dist;
    index index.html;

    location / {
        try_files $uri $uri/ /index.html;
    }

    location /api/ {
        proxy_pass http://localhost:3001;
    }

    location /health {
        proxy_pass http://localhost:3001;
    }
}
```

> ⚠️ 已知限制：前端 5 个页面硬编码 `ws://${hostname}:3001` 直连后端 WebSocket，
> 反向代理**并未收口** 3001 端口（须对浏览器可达），且 HTTPS 部署下会被混合内容
> 策略拦截（需改前端 WS_URL 为 wss 相对路径——规划项）。

```bash
# 开发模式（前后端热重载）
cd web/frontend && npm run dev -- --host 0.0.0.0 &   # --host 使局域网可访问（vite 默认只绑 localhost）
cd web/backend  && npm run dev &
# 前端: http://localhost:5173
# 后端: http://localhost:3001
```

---

## 第五步：Home Assistant 集成

```bash
# 1. 在 HA 中安装 Mosquitto broker 插件
# 2. 复制 ha/ 配置到 HA
scp -r ha/ homeassistant:/config/packages/fan-controller/

# 3. 在 configuration.yaml 中添加:
cat >> /config/configuration.yaml << 'EOF'
homeassistant:
  packages:
    fan_controller: !include_dir_named packages/fan-controller
EOF

# 4. 重启 HA → 设备自动出现在 集成 → MQTT
```

---

## 第六步：OTA 固件更新

OTA 更新支持两种方式：

**方式1：通过 Web APP**
1. 打开 `http://localhost:5173/devices`
2. 在目标设备行中输入固件 HTTPS URL
3. 点击 `Flash OTA`

**方式2：通过 MQTT 命令**
```bash
mosquitto_pub -h localhost \
  -t "fan-controller/esp32-a1b2c3/command/ota" \
  -m '{"firmware_url":"https://your-server.com/v1.1.0.bin","timestamp":0}'
```

回滚保护：新固件需在30秒内启动、2分钟内连网、5分钟内首次MQTT通信，否则自动回滚。

---

## 故障排查 FAQ

| 问题 | 原因 | 解决方法 |
|---|---|---|
| LED 蓝色慢闪 | WiFi 断连 | 检查路由器信号，或长按配网键重新配网 |
| LED 红色快闪 | 告警 (温度/停转) | 检查风扇接线和服务器温度 |
| ESP32 无法识别串口 | USB 驱动 | ESP32-S3 使用原生 USB-OTG，无需驱动，但需 Linux udev 规则：`echo 'SUBSYSTEM=="usb", ATTRS{idVendor}=="303a", MODE="0666"' | sudo tee /etc/udev/rules.d/99-esp32.rules` |
| Go Agent 找不到串口 | 串口路径错误 | `ls /dev/ttyACM*` 确认路径，更新 config.yaml |
| Agent 启动即退出（status=216/GROUP） | 旧版 service 的 `Group=nobody` 在 Debian/Ubuntu 上不存在（组名为 nogroup） | 更新仓库后重跑 `install.sh` 覆盖 unit；或临时 drop-in：`printf '[Service]\nGroup=nogroup\n' > /etc/systemd/system/smart-fan-agent.service.d/10-group.conf && systemctl daemon-reload` |
| go build 报 `go.mod requires go >= 1.25.0` | 系统工具链低于 go.mod 要求 | 安装 Go 1.25+；或保持默认 `GOTOOLCHAIN=auto` 允许联网下载工具链（离线环境必须手动装） |
| MQTT 数据不更新 | Broker 地址错误 | 检查 firmware NVS 中的 broker URL，USB 命令: `wifi status` |
| Web APP 无设备 | MQTT 未订阅 | 检查后端日志: `[mqtt] connected to ...` |

---

## 验证命令

```bash
# 固件
cd firmware && idf.py build         # BUILD SUCCESS

# Go Agent
cd agent && go build ./... && go test ./...   # PASS

# Web APP
cd web/backend  && npm run build    # 无错误
cd web/frontend && npm run build    # dist/ 生成

# 系统冒烟测试（脚本已带可执行位，无需 chmod）
./test/smoke_test.sh localhost localhost 2>&1 | tee smoke.log
grep "PASS\|FAIL" smoke.log
# 期望输出: PASS: 25  FAIL: 0（任一 FAIL 退出码非 0）
# 注: 25 项中 8 项为静态断言（CP11/CP12/CP14 部分只检查 ha/*.yaml 与文档），
#     与运行状态无关；运行时链路以其余 17 项为准
```

---

## Web 层安全声明（局域网假设）

Web 后端当前监听 `0.0.0.0:3001` 且 CORS 全开、REST API 无鉴权——**仅适用于
可信局域网**（homelab/内网机房）。请勿将 3001 端口直接暴露到公网；如需外网
访问，请置于反向代理 + VPN（如 Tailscale/WireGuard）之后。简单 token 鉴权
为规划项。

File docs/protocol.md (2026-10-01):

# MQTT协议规范 - 服务器智能风扇控制系统

**版本**: v1.0.1

**最后更新**: 2026-08-25

---

## 概述

本系统使用MQTT 3.1.1协议作为统一通信层，连接ESP32-S3固件、Go Linux Agent、Web后端和Home Assistant。所有设备通过MQTT Broker（推荐Mosquitto/EMQX）进行消息交换。

**核心原则**:
- 所有JSON消息必须包含 `timestamp`（Unix秒）和 `device_id`（设备唯一标识）
- QoS 0用于高频遥测数据（传感器读数），QoS 1用于控制指令和告警
- Last Will Testament (LWT) 用于设备在线状态管理
- Home Assistant 集成：现行方案为 `ha/` 手动 packages；MQTT Discovery 为规划项（§8）

---

## Topic命名空间

统一前缀: `fan-controller/{device_id}/`

| Topic类别 | Topic模板 | QoS | 方向 | 说明 |
|---|---|:---:|:----:|---|
| **Status** | `fan-controller/{device_id}/status` | 1 | 设备→Broker | 设备在线状态（LWT遗嘱消息，retain）|
| **Sensor** | `fan-controller/{device_id}/sensor/{type}` | 0 | 设备→Broker | 传感器数据上报 |
| **Sensor(buffered)** | `fan-controller/{device_id}/sensor/{type}/buffered` | 0 | 设备→Broker | 离线补发（§10） |
| **Fan** | `fan-controller/{device_id}/fan/{index}/state` | 0 | 设备→Broker | 风扇状态上报 |
| **Command** | `fan-controller/{device_id}/command/{action}` | 1 | Broker→设备 | 控制指令下发 |
| **Alert(事件)** | `fan-controller/{device_id}/alert` | 1 | 设备→Broker | 告警触发事件（web 消费） |
| **Alert(状态)** | `fan-controller/{device_id}/alert/{type}/state` | 1 | 设备→Broker | per-type retained 告警状态（HA 消费，§5.1） |
| **Config** | `fan-controller/{device_id}/config/{section}` | 1 | 双向 | 配置更新（§6，仅 alert 已实现） |
| **OTA** | `fan-controller/{device_id}/command/ota` | 1 | Broker→设备 | 固件更新触发（§7） |
| **OTA状态** | `fan-controller/{device_id}/ota/status` | 1 | 设备→Broker | OTA 进度反馈（§7） |
| **Discovery** | `homeassistant/{component}/{device_id}/{object_id}/config` | 1 | 设备→Broker | HA 自动发现（**规划中，未实现**，§8） |

- **{device_id}**: 设备唯一标识，格式 `esp32-XXXXXX`（ESP32-S3 MAC地址后6位）
- **{type}**: 传感器类型 `bme280`, `ds18b20`, `voltage`, `internal_temp`
- **{index}**: 风扇索引 `0` ~ `7`（8 路，硬件 v1.2）
- **{action}**: 控制动作 `fan`, `curve`, `reboot`, `reset`, `ota`
- **{section}**: 配置段 `wifi`, `mqtt`, `alert`, `curve`（wifi/mqtt 为规划中，§6）
- **{type}(alert)**: 告警类型 `temperature_high`, `fan_stall`, `voltage_abnormal`, `wifi_disconnected`

---

## 1. Status — 设备状态（LWT）

### 1.1 设备上线

**Topic**: `fan-controller/{device_id}/status`  
**Payload**:
```json
{
  "timestamp": 1722315503,
  "device_id": "esp32-a1b2c3",
  "status": "online",
  "firmware_version": "v1.0.0",
  "ip_address": "192.168.1.100",
  "uptime_seconds": 3600
}
```

### 1.2 设备离线（LWT遗嘱）

**Payload**:
```json
{
  "timestamp": 1722315503,
  "device_id": "esp32-a1b2c3",
  "status": "offline"
}
```

**MQTT连接参数**:
- LWT Topic: `fan-controller/{device_id}/status`
- LWT Payload: 离线JSON（含 timestamp/device_id/status 三字段）
- LWT QoS: 1
- LWT Retain: true

**timestamp 语义（v1.0.1/ADJ-1）**: 统一为 Unix 秒（`time(NULL)`）。设备 SNTP
未同步时上报值为 Unix 早期值（< 1000000000），消费方应显示"时间未同步"而非
按 1970 年日期渲染。

---

## 2. Sensor — 传感器数据

### 2.1 BME280环境传感器

**Topic**: `fan-controller/{device_id}/sensor/bme280`  
**频率**: 1秒  
**Payload**:
```json
{
  "timestamp": 1722315503,
  "device_id": "esp32-a1b2c3",
  "temperature_c": 25.3,
  "humidity_pct": 45.2,
  "pressure_hpa": 1013.25
}
```

### 2.2 DS18B20远程温度探头

**Topic**: `fan-controller/{device_id}/sensor/ds18b20`  
**频率**: 1秒  
**Payload**:
```json
{
  "timestamp": 1722315503,
  "device_id": "esp32-a1b2c3",
  "sensors": [
    {"address": "28-00000a1b2c3d", "temperature_c": 35.5, "valid": true},
    {"address": "28-00000e4f5g6h", "temperature_c": 42.1, "valid": true}
  ]
}
```

### 2.3 电源电压监控

**Topic**: `fan-controller/{device_id}/sensor/voltage`  
**频率**: 5秒  
**Payload**:
```json
{
  "timestamp": 1722315503,
  "device_id": "esp32-a1b2c3",
  "voltage_12v": 12.05,
  "voltage_5v": 5.02,
  "voltage_3v3": 3.31
}
```

### 2.4 ESP32内部温度

**Topic**: `fan-controller/{device_id}/sensor/internal_temp`  
**频率**: 5秒  
**Payload**:
```json
{
  "timestamp": 1722315503,
  "device_id": "esp32-a1b2c3",
  "temperature_c": 45.2
}
```

---

## 3. Fan — 风扇状态

### 3.1 风扇状态上报

**Topic**: `fan-controller/{device_id}/fan/{index}/state`  
**频率**: 1秒（每路风扇独立发布）  
**Payload**:
```json
{
  "timestamp": 1722315503,
  "device_id": "esp32-a1b2c3",
  "fan_index": 0,
  "pwm_duty_pct": 65,
  "rpm": 1850,
  "stalled": false,
  "mode": "auto"
}
```

**字段说明**:
- `pwm_duty_pct`: PWM占空比百分比 (0-100)
- `rpm`: 转速（转/分钟）
- `stalled`: 停转检测（true=风扇停转）
- `mode`: 控制模式 `"auto"`（自动曲线）或 `"manual"`（手动）

---

## 4. Command — 控制指令

### 4.1 风扇转速控制

**Topic**: `fan-controller/{device_id}/command/fan`  
**Payload**:
```json
{
  "timestamp": 1722315503,
  "device_id": "esp32-a1b2c3",
  "fan_index": 0,
  "mode": "manual",
  "duty_pct": 75
}
```

**响应**: 设备通过 `fan/{index}/state` 上报新状态

### 4.2 风扇曲线配置

**Topic**: `fan-controller/{device_id}/command/curve`  
**Payload（固定查表LUT模式）**:
```json
{
  "timestamp": 1722315503,
  "device_id": "esp32-a1b2c3",
  "fan_index": 0,
  "mode": "lut",
  "temperature_source": "bme280",
  "points": [
    {"temp_c": 30, "duty_pct": 20},
    {"temp_c": 40, "duty_pct": 40},
    {"temp_c": 50, "duty_pct": 60},
    {"temp_c": 60, "duty_pct": 80},
    {"temp_c": 70, "duty_pct": 100}
  ]
}
```

**Payload（PID自适应模式）**:
```json
{
  "timestamp": 1722315503,
  "device_id": "esp32-a1b2c3",
  "fan_index": 0,
  "mode": "pid",
  "temperature_source": "ds18b20_0",
  "setpoint_c": 50.0,
  "kp": 2.0,
  "ki": 0.1,
  "kd": 0.5
}
```

**字段说明**:
- `temperature_source`（枚举，4 个合法值）: `bme280` / `ds18b20_0` / `ds18b20_1` / `internal`
- PID 参数（`setpoint_c`/`kp`/`ki`/`kd`）平铺在 payload 顶层（不嵌套 `pid` 对象）
- LUT `points` 的 `temp_c` 必须严格递增（乱序将被固件拒绝），点数上限 10

### 4.3 设备重启

**Topic**: `fan-controller/{device_id}/command/reboot`  
**Payload**:
```json
{
  "timestamp": 1722315503,
  "device_id": "esp32-a1b2c3"
}
```

### 4.4 恢复出厂设置

**Topic**: `fan-controller/{device_id}/command/reset`  
**Payload**:
```json
{
  "timestamp": 1722315503,
  "device_id": "esp32-a1b2c3",
  "confirm": true
}
```

---

## 5. Alert — 告警消息

### 5.1 告警触发事件（web 消费）

**Topic**: `fan-controller/{device_id}/alert`  
**Payload**:
```json
{
  "timestamp": 1722315503,
  "device_id": "esp32-a1b2c3",
  "alert_type": "temperature_high",
  "severity": "critical",
  "message": "温度超过阈值: BME280 = 78.5°C (阈值75°C)",
  "value": 78.5,
  "threshold": 75.0,
  "sensor": "bme280"
}
```

**告警类型** (`alert_type`，字符串枚举):
- `temperature_high`: 温度过高（三源最大值，含 DS18B20 探头）
- `fan_stall`: 风扇停转（duty>5% 且 RPM<200，0% 占空比合法停转除外）
- `voltage_abnormal`: 电压异常
- `wifi_disconnected`: WiFi断开超过60秒

**严重性** (`severity`):
- `warning`: 警告（黄色LED）
- `critical`: 严重（红色LED）

### 5.2 per-type 告警状态 topic（HA 消费，retained）

**Topic**: `fan-controller/{device_id}/alert/{type}/state`（retain=true）

每类告警独立的状态 topic，触发/恢复时更新，四类互不干扰：

**Payload**:
```json
{
  "active": true,
  "severity": "warning",
  "timestamp": 1722315503
}
```

- `active`: 当前告警是否处于激活状态（恢复时发布 `false`）
- HA 的 binary_sensor 订阅此 topic，按 `value_json.active` 判定

**告警阈值模型（双阈值，v1.0.1 裁决 ADJ-14）**:

| 维度 | 阈值 |
|---|---|
| 温度 | 75°C 警告（warning）/ 80°C critical |
| 12V 电压 | 窗口 10.8 – 13.2V |
| 5V 电压 | 5V ± 0.25V |
| 3.3V 电压 | 3.3V ± 0.165V |
| 风扇停转 | duty > 5% 且 RPM < 200 |
| WiFi 断连 | > 60 秒 |

---

## 6. Config — 配置管理

> **实现状态（v1.0.1 / ADJ-9）**：`config/alert` 已实现（set 保存 NVS+应用，get 回读）；
> `config/wifi` 与 `config/mqtt` **规划中，现行经 USB console 命令配置**
> （`wifi status|reset`、`mqtt status|set <url>`，见 deploy.md §1.4）。

### 6.1 WiFi配置（规划中 — 现行经 USB console）

**Topic**: `fan-controller/{device_id}/config/wifi`  
**Payload**:
```json
{
  "timestamp": 1722315503,
  "device_id": "esp32-a1b2c3",
  "ssid": "MyNetwork",
  "password": "********"
}
```

### 6.2 告警规则配置（已实现，双阈值模型）

**Topic**: `fan-controller/{device_id}/config/alert`  
**Payload（set）**:
```json
{
  "timestamp": 1722315503,
  "device_id": "esp32-a1b2c3",
  "rules": [
    {"type": "temperature_high", "warn_c": 75.0, "crit_c": 80.0, "enabled": true},
    {"type": "fan_stall", "threshold": 200, "enabled": true},
    {"type": "voltage_abnormal", "12v_min": 10.8, "12v_max": 13.2, "enabled": true},
    {"type": "wifi_disconnected", "threshold": 60, "enabled": true}
  ]
}
```

**Payload（get 回读）**: 发布 `{"get": true}` 到同一 topic，设备回发当前生效规则。

---

## 7. OTA — 固件更新

**Topic**: `fan-controller/{device_id}/command/ota`

（v1.0.1/ADJ-3：与命令命名空间一致，原 `{id}/ota` 写法已废止）

**Payload**:
```json
{
  "timestamp": 1722315503,
  "device_id": "esp32-a1b2c3",
  "firmware_url": "https://example.com/firmware/v1.1.0.bin",
  "version": "v1.1.0",
  "checksum_sha256": "a1b2c3..."
}
```

**OTA状态反馈**:

**Topic**: `fan-controller/{device_id}/ota/status`  
**Payload**:
```json
{
  "timestamp": 1722315503,
  "device_id": "esp32-a1b2c3",
  "state": "downloading",
  "progress_pct": 45,
  "message": "Downloading firmware..."
}
```

**状态值** (`state`):
- `downloading`: 下载中
- `verifying`: 校验中
- `flashing`: 烧录中
- `success`: 成功（即将重启）
- `failed`: 失败

---

## 8. Home Assistant MQTT Discovery（规划中，未实现）

> **v1.0.1 / ADJ-10**：固件当前不发布 Discovery 配置。现行 HA 集成方案为
> `ha/` 目录的手动 packages（见 ha/README.md）。以下为本节保留的规划设计。

### 8.1 设备实体配置

**Topic**: `homeassistant/sensor/{device_id}/temperature/config`  
**Payload**:
```json
{
  "name": "Fan Controller Temperature",
  "device_class": "temperature",
  "state_topic": "fan-controller/esp32-a1b2c3/sensor/bme280",
  "value_template": "{{ value_json.temperature_c }}",
  "unit_of_measurement": "°C",
  "unique_id": "esp32_a1b2c3_temp",
  "device": {
    "identifiers": ["esp32-a1b2c3"],
    "name": "Smart Fan Controller",
    "model": "ESP32-S3-N16R8",
    "manufacturer": "DIY",
    "sw_version": "v1.0.0"
  }
}
```

### 8.2 风扇实体（可控）

**Topic**: `homeassistant/fan/{device_id}/fan0/config`  
**Payload**:
```json
{
  "name": "Fan 0",
  "command_topic": "fan-controller/esp32-a1b2c3/command/fan",
  "state_topic": "fan-controller/esp32-a1b2c3/fan/0/state",
  "percentage_command_topic": "fan-controller/esp32-a1b2c3/command/fan",
  "percentage_state_topic": "fan-controller/esp32-a1b2c3/fan/0/state",
  "percentage_value_template": "{{ value_json.pwm_duty_pct }}",
  "payload_on": "{\"fan_index\":0,\"mode\":\"manual\",\"duty_pct\":100}",
  "payload_off": "{\"fan_index\":0,\"mode\":\"manual\",\"duty_pct\":0}",
  "unique_id": "esp32_a1b2c3_fan0",
  "device": {
    "identifiers": ["esp32-a1b2c3"]
  }
}
```

---

## 9. 消息流示例

### 9.1 启动流程

```mermaid
sequenceDiagram
    ESP32->>MQTT: CONNECT (LWT设置为offline)
    ESP32->>MQTT: PUBLISH status=online
    ESP32->>MQTT: SUBSCRIBE fan-controller/{device_id}/command/# 与 config/#
    ESP32->>MQTT: PUBLISH sensor/bme280 (每秒)
    ESP32->>MQTT: PUBLISH fan/*/state (每秒)
```

### 9.2 风扇手动控制

```mermaid
sequenceDiagram
    WebAPP->>MQTT: PUBLISH command/fan {fan_index:0, duty_pct:75}
    MQTT->>ESP32: RECEIVE command/fan
    ESP32->>Hardware: 设置LEDC PWM占空比75%
    ESP32->>MQTT: PUBLISH fan/0/state {pwm_duty_pct:75, rpm:2100}
    MQTT->>WebAPP: UPDATE UI显示新状态
```

### 9.3 温度告警

```mermaid
sequenceDiagram
    ESP32->>ESP32: BME280读数78.5°C > 阈值75°C
    ESP32->>Hardware: 设置RGB LED为红色闪烁
    ESP32->>MQTT: PUBLISH alert {type:temperature_high}
    MQTT->>WebAPP: 显示告警通知
    MQTT->>GoAgent: 转发至系统日志
    MQTT->>HomeAssistant: 触发自动化（如发送通知）
```

---

## 10. 离线消息队列

当设备断网时，固件将最多缓存 **50条** 消息到Flash存储（`storage`分区）：
- 传感器数据: 每30秒采样1次（降频）
- 告警消息: 全部保留
- 风扇状态: 每30秒采样1次

重连后批量发送，Topic后缀添加 `/buffered`：
```
fan-controller/{device_id}/sensor/bme280/buffered
```

Payload增加 `buffered: true` 标记：
```json
{
  "timestamp": 1722315503,
  "device_id": "esp32-a1b2c3",
  "buffered": true,
  "temperature_c": 25.3,
  "humidity_pct": 45.2,
  "pressure_hpa": 1013.25
}
```

---

## 11. 实现注意事项

### ESP32固件侧
- 使用 `esp_mqtt_client_config_t.lwt_topic/lwt_msg` 配置LWT
- 所有JSON消息用 `cJSON` 库构造（不用 `sprintf`）
- 订阅通配符 `fan-controller/{device_id}/command/#`
- `device_id` 从ESP32 MAC地址生成：`esp32-` + MAC后6位hex

### Go Agent侧
- 订阅 `fan-controller/+/sensor/#` 监听所有设备传感器数据
- 订阅 `fan-controller/+/alert` 接收告警转发至系统日志
- 发布本机指标到 `system-monitor/{hostname}/sensor/{collector}`，collector 为采集器名：
  `system`（CPU/内存/磁盘/负载）与 `gpu`（nvidia-smi；无 GPU 时自动禁用、该 topic 不发布）
- 注意：该 topic 不在 `fan-controller/#` 之下，Web 后端不订阅、控制台不显示，仅供 MQTT 订阅方消费

### Web后端侧
- WebSocket每2秒向前端推送最新缓存的设备状态
- 订阅所有设备的 `status` Topic维护在线设备列表
- 控制指令从REST API转换为MQTT PUBLISH

### Home Assistant侧
- 现行方案为 `ha/` 手动 packages 配置（ha/README.md 安装步骤）
- MQTT Discovery 自动发现为**规划项**，固件当前不发布 Discovery 配置（§8）
- 实体 `unique_id` 必须全局唯一
- `state_topic` 和 `command_topic` 必须匹配协议规范

---

## 12. 协议版本演进

**v1.0** (2026-07-30):
- 基础传感器/风扇/告警/OTA功能

**v1.0.1** (2026-08-25，模块整改 v1.2 修订，依据 docs/module-remediation-plan-v1.2.md §1 裁决表):
- ADJ-3: OTA 触发 topic 统一为 `command/ota`（原 `{id}/ota` 废止）
- ADJ-8: §5 补录 per-type retained 状态 topic `alert/{type}/state`
- ADJ-5: §4.2 `temperature_source` 枚举 4 值（bme280/ds18b20_0/ds18b20_1/internal）
- ADJ-9: §6 wifi/mqtt 配置标注"规划中，现行经 USB console 配置"
- ADJ-10: §8/§11 Discovery 标注"规划中，现行方案为 ha/ 手动 packages"
- ADJ-13: 风扇路数口径统一为 8 路（{index} 0-7）
- ADJ-14: §5/§6.2 阈值示例改为双阈值模型（温度 75/80、12V 10.8-13.2、停转 duty>5%且<200RPM、WiFi 60s）
- ADJ-6: §2.2 ds18b20 sensors[] 按 address/valid 匹配的口径确认（无效项也上报）

**未来计划**:
- v1.1: 增加风扇曲线配置历史记录
- v1.2: 支持多个MQTT Broker备份
- v2.0: 支持MQTT 5.0协议（增强认证和元数据）

---

**文档结束**

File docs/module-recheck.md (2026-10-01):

# 模块一致性复验报告（module-recheck）

> 依据：`docs/module-remediation-plan-v1.2.md` §6.3；矩阵格式按 `docs/module-review-plan.md` §8。
> 复验日期：2026-08-25（整改完成后）。全部结论基于整改后代码 grep/构建实测。

---

## 表1 — MQTT topic 一致性（19 行）

左=protocol.md v1.0.1 topic 清单；右=四方实际使用。

| # | Topic（protocol.md） | 固件 | web backend | agent | ha | 结果 |
|---|---|---|---|---|-----|---|
| 1 | `{id}/status`（online, retain） | mqtt_wrapper CONNECTED 发布（retain=1）✓ | mqtt.ts 订阅 ✓ | — | alerts.yaml online 实体 + 全实体 availability ✓ | ✓ |
| 2 | `{id}/status`（LWT offline, retain） | connect() LWT 配置 ✓ | online=false 解析 ✓ | — | availability_template 判 offline ✓ | ✓ |
| 3 | `{id}/sensor/bme280` | sensor_task 1s ✓ | mqtt.ts sensor/# ✓ | agent.go 订阅 sensor/# ✓ | sensors.yaml ✓ | ✓ |
| 4 | `{id}/sensor/ds18b20` | address/valid schema（FW-18）✓ | types.ts address/valid ✓ | 订阅 ✓ | selectattr address ✓ | ✓ |
| 5 | `{id}/sensor/voltage` | 5s（FW-19）✓ | voltage 解析 ✓ | 订阅 ✓ | 3 实体（12V/5V/3.3V）✓ | ✓ |
| 6 | `{id}/sensor/internal_temp` | 5s ✓ | internal_temp ✓ | 订阅 ✓ | MCU 温度实体 ✓ | ✓ |
| 7 | `{id}/sensor/{type}/buffered` | flush_one 后缀 ✓（FW-07④） | sensor/# 吃到 ✓（CP17） | 订阅 sensor/# ✓ | 同 schema ✓ | ✓ |
| 8 | `{id}/fan/{0-7}/state` | tach_monitor 1s×8 ✓ | fan/+/state 解析 idx<FAN_COUNT ✓ | — | 8 RPM 实体 ✓ | ✓ |
| 9 | `{id}/command/fan` | handler ✓（越界丢弃） | devices.ts 发布 ✓ | —（AG-04 删除订阅） | fans.yaml command_topic ✓ | ✓ |
| 10 | `{id}/command/curve` | handler（FW-20①）✓ | curve 端点发布 ✓ | — | — | ✓ |
| 11 | `{id}/command/reboot` | handler ✓ | reboot 端点 ✓ | — | — | ✓ |
| 12 | `{id}/command/reset` | handler confirm 门 ✓（FW-20③） | —（无端点，协议直发） | — | — | ✓ |
| 13 | `{id}/command/ota` | handler（ADJ-3）✓ | ota 端点 ✓ | — | — | ✓ |
| 14 | `{id}/ota/status` | ota_publish_status（FW-10）✓ | 订阅+WS 转发（WEB-04）✓ | — | — | ✓ |
| 15 | `{id}/alert`（事件） | on_alert（§5.1 全字段）✓ | 订阅+alerts 缓存 ✓ | agent 订阅 `+/alert` 转发日志 ✓ | —（HA 改用状态 topic） | ✓ |
| 16 | `{id}/alert/{type}/state` | publish_alert_state（FW-17）✓ | — | — | alerts.yaml 4 实体 ✓ | ✓ |
| 17 | `{id}/config/alert` | 订阅 config/# + set/get（FW-20④）✓ | publishConfig（WEB-05）✓ | — | — | ✓ |
| 18 | `{id}/config/{wifi,mqtt}` | 协议标注"规划中，经 USB console"；固件未订阅 ✓（口径一致） | — | — | — | ✓（DESCOPE(ADJ-9) 一致降级） |
| 19 | `homeassistant/.../config`（Discovery） | 未实现，协议标注规划中 ✓ | — | — | ha/ 手动 packages ✓ | ✓（DESCOPE(ADJ-10) 一致裁剪） |

**结论：19/19 ✓**（其中 2 行为按裁决一致降级/裁剪，非分叉）。

---

## 表2 — 风扇数量与索引（15 处口径）

唯一基准 = 硬件决策 D2 = **8 路**，0 基索引。

| 位置 | 数值 | 结果 |
|---|---|---|
| firmware fan_pwm.h FAN_PWM_COUNT | 8 | ✓ |
| firmware fan_pwm.c FAN_GPIO[] | {5..12} 8 元素 | ✓ |
| firmware fan_tach.h FAN_TACH_COUNT | 8 | ✓ |
| firmware fan_tach.c TACH_GPIO[] | 8 元素（4 unit×2 ch） | ✓ |
| firmware fan_curve.h FAN_CURVE_FANS | 8 | ✓ |
| firmware alert_manager ALERT_FAN_COUNT | 8 | ✓ |
| firmware flash_storage.h fan_rpm[] | [8] | ✓ |
| firmware main.c 三处循环 | FAN_TACH_COUNT 引用 | ✓ |
| web backend types.ts FAN_COUNT | 8（导出常量） | ✓ |
| web backend mqtt.ts fans 数组/idx 边界 | FAN_COUNT | ✓ |
| web frontend Fans/History/FanCard | 遍历 device.fans（8）+ FAN_COUNT=8 | ✓ |
| ha fans.yaml fan 实体 | 8（Fan 0-7） | ✓ |
| ha sensors.yaml RPM 实体 | 8 | ✓ |
| protocol.md {index} 定义 | 0-7 | ✓ |
| README 架构图/特性/硬件表/Web 节 | 8 路 | ✓ |

**结论：15/15 ✓**。grep 门 `FAN_PWM_COUNT 4|FAN_CURVE_FANS 4|fan_rpm[4]|length: 4|idx < 4` 全空。

---

## 表3 — 命令名与 payload（9 条命令口径）

| 命令 | 固件实现 | 协议 §4/§6 | web 构造 | ha 模板 | 结果 |
|---|---|---|---|---|---|
| console `help` | 动态列出 7 命令 | —（console 不在协议） | — | — | ✓ 与 deploy/assembly 示例一致 |
| console `status` | cmd_status（JSON） | — | — | — | ✓ |
| console `fan <0-7> <0-100>` | cmd_fan（越界拒绝） | — | — | — | ✓（DOC-02 对齐） |
| console `wifi status\|reset` | cmd_wifi | —（ADJ-9 降级承接） | — | — | ✓ |
| console `mqtt status\|set <url>` | cmd_mqtt（scheme 校验） | —（ADJ-9） | — | — | ✓ |
| console `ota <url>` / `reboot` | 既有 ✓ | — | — | — | ✓ |
| `command/fan` | fan_index+mode+duty_pct，越界丢弃 | §4.1 一致 | `{fan_index, mode:'manual', duty_pct, timestamp}` | fans.yaml 模板一致 | ✓ |
| `command/curve` | §4.2：points/LUT、PID 平铺、source 枚举映射、严格递增校验 | §4.2 一致（ADJ-4/5） | CurveSchema 平铺+枚举 zod | — | ✓ |
| `command/reset` / `config/alert` | confirm 门 / rules set-get+NVS | §4.4/§6.2 一致（ADJ-14 双阈值） | alert 端点→config/alert | — | ✓ |
| `command/ota` | firmware_url 触发 + ota/status 反馈 | §7 一致（ADJ-3） | ota 端点 | — | ✓ |

**结论：全部 ✓**（9 行命令口径 + console 命令集）。

---
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

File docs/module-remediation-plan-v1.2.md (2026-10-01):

# 模块整改清单 v1.2（Module Remediation Plan）

> 依据：`docs/module-review-report.md` v1.0（2026-08-24，75 条发现：12 Critical / 32 Major / 27 Minor / 4 Info）。
> 硬件部分（原理图/PCB/BOM/硬件文档）由 `hardware/docs/remediation-plan-v1.2.md`（v1.2.1）承接，
> 本清单只负责固件非引脚类问题与 agent / web / ha / test / docs——唯一例外是指针项 Phase 0-7（执行硬件清单 H-03）。
> 本文档是给整改执行 agent 的**唯一权威依据**；与审查报告"建议修法"冲突时以本文档的裁决为准。

---

## 0. 执行总则（防偷懒硬规则）
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

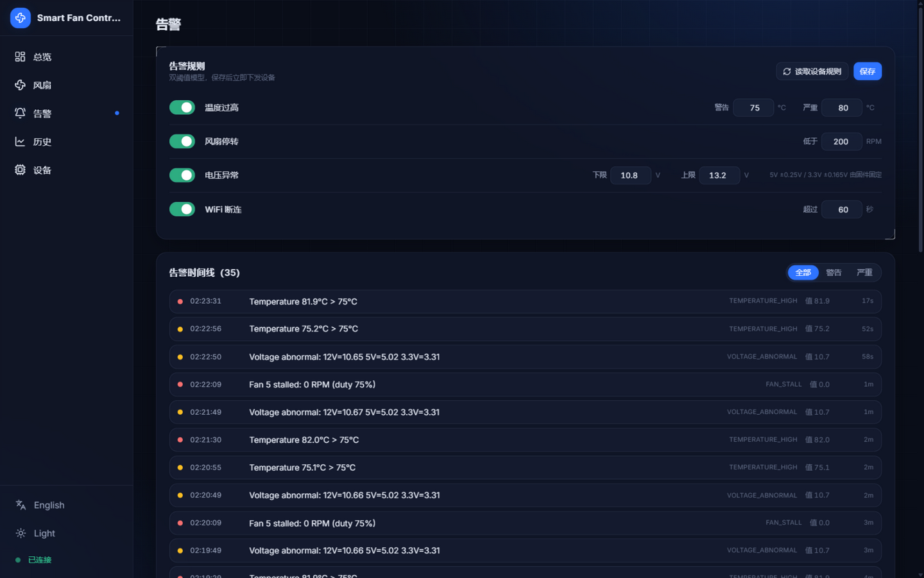
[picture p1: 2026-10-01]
docs/verification/redesign-evidence/alerts-dark-zh.png

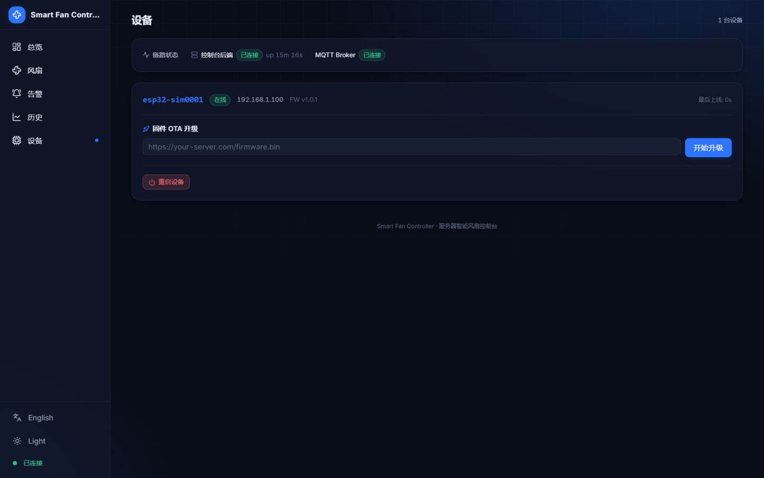
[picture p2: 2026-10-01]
docs/verification/redesign-evidence/devices-dark-zh.png

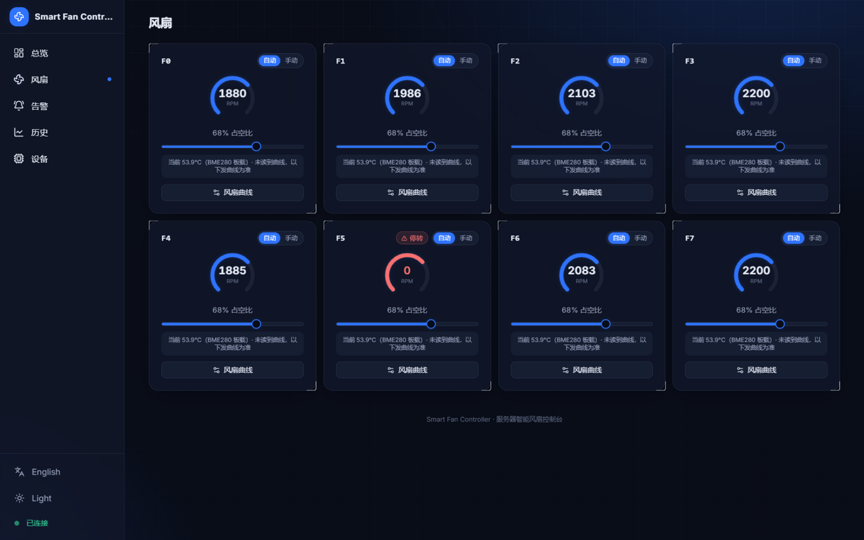
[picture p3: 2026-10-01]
docs/verification/redesign-evidence/fans-dark-zh.png

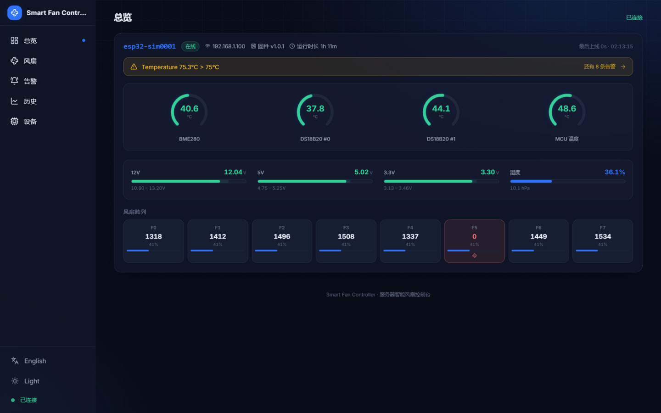
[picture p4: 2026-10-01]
docs/verification/redesign-evidence/dashboard-dark-zh.png

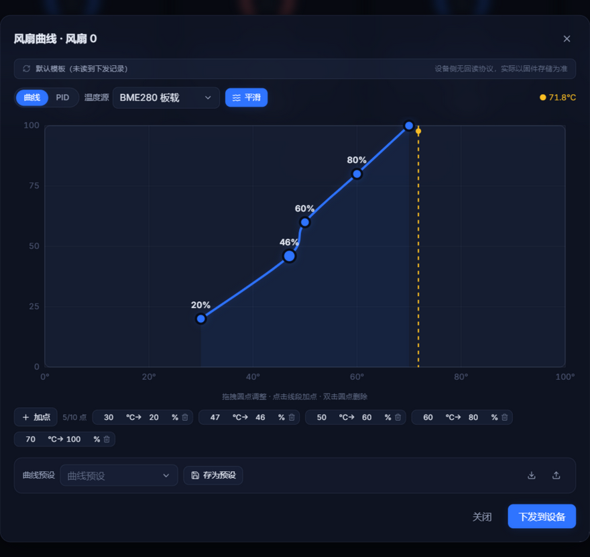
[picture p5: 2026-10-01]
docs/verification/redesign-evidence/curve-drawer-drag.png

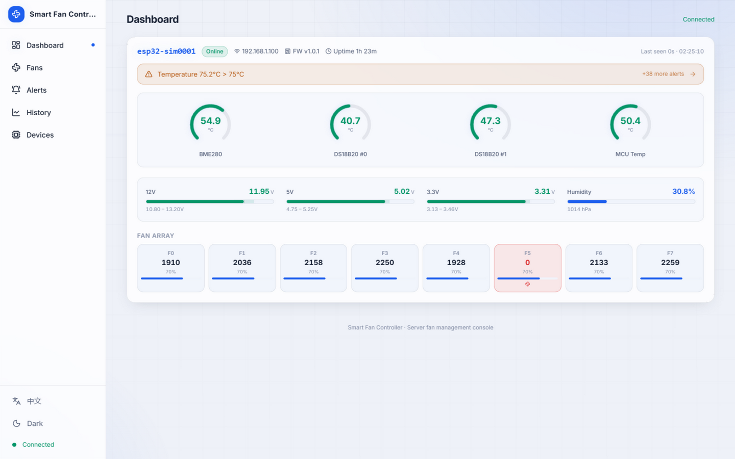
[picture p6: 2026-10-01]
docs/verification/redesign-evidence/dashboard-light-en.png

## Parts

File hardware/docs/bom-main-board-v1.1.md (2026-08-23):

# BOM (Bill of Materials) - 主控板 v1.1

## 核心元件

| 序号 | 位号 | 元件名称 | 型号/规格 | 封装 | 数量 | LCSC编号 | 单价(¥) | 小计(¥) | 嘉立创购买链接 | 淘宝关键词 |
|:---:|:----:|---|---|---|:----:|:---:|:---:|:---:|---|---|
| 1 | U1 | LDO稳压器 | AMS1117-3.3 | SOT-223 | 1 | C6186 | 0.15 | 0.15 | https://item.szlcsc.com/6186.html | AMS1117-3.3 SOT223 |
| 2 | U2 | ESP32模组 | ESP32-S3-WROOM-1-N16R8 | SMD | 1 | C2913202 | 18.50 | 18.50 | https://item.szlcsc.com/2913202.html | ESP32-S3 16MB 8MB |
| 3 | U3 | 电平转换芯片 | 74AHCT125D | SOIC-14 | 2 | C6082 | 0.25 | 0.50 | https://item.szlcsc.com/6082.html | 74AHCT125 SOIC14 |
| 4 | U4 | 环境传感器 | BME280 | LGA-8 | 1 | C92489 | 5.80 | 5.80 | https://item.szlcsc.com/92489.html | BME280 温湿度气压 |
| 5 | U5 | ESD保护 | USBLC6-2SC6 | SOT-23-6 | 1 | C7519 | 0.18 | 0.18 | https://item.szlcsc.com/7519.html | USBLC6 USB保护 |
| 6 | LED1 | RGB LED | WS2812B-2020 | 2020 | 1 | C2761795 | 0.12 | 0.12 | https://item.szlcsc.com/2761795.html | WS2812B 2020封装 |
| 7 | D1 | 肖特基二极管 | SS34 | SMA | 1 | C8678 | 0.08 | 0.08 | https://item.szlcsc.com/8678.html | SS34 肖特基 SMA |
| 8 | D2 | 肖特基二极管 | B5819W | SOD-123 | 1 | C8598 | 0.05 | 0.05 | https://item.szlcsc.com/8598.html | B5819W 肖特基 |
| 9 | F1 | PTC保险丝 | MF-MSMF250 | 1812 | 1 | C17371 | 0.25 | 0.25 | https://item.szlcsc.com/17371.html | PTC 2A 1812 |
| 10 | F2 | PTC保险丝 | MF-MSMF100 | 1812 | 1 | C17370 | 0.22 | 0.22 | https://item.szlcsc.com/17370.html | PTC 1A 1812 |

## 连接器

| 序号 | 位号 | 元件名称 | 型号/规格 | 数量 | LCSC编号 | 单价(¥) | 小计(¥) | 嘉立创购买链接 | 淘宝关键词 |
|:---:|:----:|---|---|:----:|:---:|:---:|:---:|---|---|
| 11 | J1 | SATA电源座 | SATA 15Pin直插母座 | 1 | C388659 | 1.20 | 1.20 | https://item.szlcsc.com/388659.html | SATA电源座 15Pin母座 |
| 12 | J2 | USB-C座 | TYPE-C 16P贴片 | 1 | C165948 | 0.45 | 0.45 | https://item.szlcsc.com/165948.html | TYPE-C 16P 贴片母座 |
| 13 | J3-J8 | 风扇座 | 4Pin 2.54mm 直插 | 6 | C86501 | 0.15 | 0.90 | https://item.szlcsc.com/86501.html | 4Pin针座 2.54间距 |
| 14 | J9,J10 | 接线端子 | XH2.54-3P 白色 | 2 | C37815 | 0.08 | 0.16 | https://item.szlcsc.com/37815.html | XH2.54 3P 直插 |
| 15 | J11 | 航插座 | PH2.0-3P 卧式 | 1 | C157929 | 0.06 | 0.06 | https://item.szlcsc.com/157929.html | PH2.0 3P 卧式 |
| 16 | J12 | 排针 | 2.54mm 8P单排 | 1 | C92410 | 0.05 | 0.05 | https://item.szlcsc.com/92410.html | 2.54排针 8P |
| 17 | H1-H4 | 安装孔 | M3铜柱/尼龙柱 | 4 | - | 0.10 | 0.40 | - | M3铜柱 10mm |

## 阻容器件 (0805封装)

| 序号 | 位号 | 元件名称 | 规格 | 数量 | LCSC编号 | 单价(¥) | 小计(¥) | 嘉立创购买链接 |
|:---:|:----:|---|---|:----:|:---:|:---:|:---:|---|
| 18 | R1-R8 | 电阻 | 10kΩ ±1% | 8 | C17414 | 0.005 | 0.04 | https://item.szlcsc.com/17414.html |
| 19 | R9-R11 | 电阻 | 4.7kΩ ±1% | 3 | C17673 | 0.005 | 0.015 | https://item.szlcsc.com/17673.html |
| 20 | R12-R13 | 电阻 | 5.1kΩ ±1% | 2 | C27834 | 0.005 | 0.01 | https://item.szlcsc.com/27834.html |
| 21 | R14 | 电阻 | 100kΩ ±1% | 1 | C149504 | 0.005 | 0.005 | https://item.szlcsc.com/149504.html |
| 22 | R15 | 电阻 | 20kΩ ±1% | 1 | C17905 | 0.005 | 0.005 | https://item.szlcsc.com/17905.html |
| 23 | R16-R17 | 电阻 | 47kΩ ±1% | 2 | C25819 | 0.005 | 0.01 | https://item.szlcsc.com/25819.html |
| 24 | R18-R19 | 电阻 | 10kΩ ±1% | 2 | C17414 | 0.005 | 0.01 | https://item.szlcsc.com/17414.html |
| 25 | R20-R31 | 电阻 | 10kΩ ±5% | 12 | C17414 | 0.005 | 0.06 | https://item.szlcsc.com/17414.html |
| 26 | C1-C20 | 电容 | 100nF (0.1µF) | 20 | C49678 | 0.007 | 0.14 | https://item.szlcsc.com/49678.html |
| 27 | C21-C25 | 电容 | 10µF 10V | 5 | C15850 | 0.02 | 0.10 | https://item.szlcsc.com/15850.html |

## 直插电容

| 序号 | 位号 | 元件名称 | 规格 | 数量 | LCSC编号 | 单价(¥) | 小计(¥) | 淘宝关键词 |
|:---:|:----:|---|---|:----:|:---:|:---:|:---:|---|
| 28 | C26-C27 | 电解电容 | 100µF 25V 6.3×7.7 | 2 | C72489 | 0.05 | 0.10 | 100µF 25V 电解电容 |
| 29 | C28 | 电解电容 | 470µF 25V 8×12 | 1 | C134508 | 0.12 | 0.12 | 470µF 25V 电解电容 |

## 开关

| 序号 | 位号 | 元件名称 | 规格 | 数量 | LCSC编号 | 单价(¥) | 小计(¥) | 淘宝关键词 |
|:---:|:----:|---|---|:----:|:---:|:---:|:---:|---|
| 30 | SW1-SW3 | 轻触开关 | 6×6×5mm 4脚 | 3 | C318884 | 0.06 | 0.18 | 6x6轻触开关 直插 |

---

## 成本汇总 (主控板 v1.1)

| 类别 | 小计(¥) | 备注 |
|---|:---:|---|
| 核心元件 | 25.85 | ESP32占大头 |
| 连接器 | 3.22 | 6个风扇座 |
| 阻容器件 | 0.465 | 0805贴片 |
| 其他 | 0.40 | PCB + 加工费 |
| **总计（单板）** | **≈30元** | 不含PCB制板费 |
| **PCB制板（5片）** | **≈50元** | 嘉立创100×70mm 2层板 |
| **单套成本** | **≈40元** | (30+50/5) |

---

## 采购建议

### 方式1：嘉立创全套采购（推荐）

1. 打开立创商城 https://www.szlcsc.com
2. 登录账号 → 我的订单 → BOM配单
3. 上传本BOM表格（Excel格式）
4. 自动匹配LCSC编号 → 加入购物车
5. 优势：一站式采购，7天到货，SMT贴片服务可选

### 方式2：淘宝+嘉立创混合

**淘宝采购（更便宜但需等待）：**
- ESP32-S3模组：搜索"ESP32-S3-WROOM-1 N16R8"，价格≈15元
- 风扇座/SATA座：搜索关键词，通常更便宜
- 电容电阻：100个起售，适合批量

**嘉立创采购（快速小批量）：**
- IC芯片（74AHCT125, BME280等）
- 贴片元件（0805阻容）
- PCB制板 + SMT贴片一条龙

### 方式3：PCB + SMT 全套代工

嘉立创提供SMT贴片服务：
- 上传Gerber + BOM + 坐标文件
- 系统自动报价（含PCB + 元件 + 贴片费）
- 5片起订，约 200-300元（含贴片）
- 优势：免焊接，直插元件自己焊即可

---

## 替代料建议

| 原型号 | 替代型号 | 备注 |
|---|---|---|
| AMS1117-3.3 | XC6206P332MR | 引脚兼容 |
| 74AHCT125 | 74HC125 | 注意阈值电压差异 |
| BME280 | BMP280 | 无湿度，仅温度+气压 |
| SS34 | 1N5822 | 3A肖特基，封装不同 |
| WS2812B-2020 | SK6812-2020 | 引脚兼容 |

---

**更新日期：** 2026-01-30  
**价格有效期：** 约3个月（元器件价格波动）  
**币种：** 人民币(¥)  
**来源：** 嘉立创商城(LCSC) + 淘宝市场调研

---

## 附录：SATA电源接口定义

```
SATA 15Pin 电源接口引脚定义：
Pin 1-3:   3.3V (本设计不使用，有PWDIS兼容性问题)
Pin 4,11:  GND
Pin 5,12:  GND
Pin 6:     GND
Pin 7-9:   5V  (→ AMS1117-3.3 输入)
Pin 10:    GND
Pin 13-15: 12V (→ 风扇供电)

本设计只使用:
- Pin 7-9 (5V)
- Pin 13-15 (12V)
- Pin 4,5,6,10,11,12 (GND)
```

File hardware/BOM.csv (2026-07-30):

Ref | Description | Value | Package | Qty | LCSC_PN | Notes
U1 | LDO 3.3V | AMS1117-3.3 | SOT-223 | 1 | C6186 | 5V→3.3V电源 散热铜皮≥2cm²
U2 | WiFi+BLE SoC | ESP32-S3-WROOM-1-N16R8 | SMD-38P | 1 | C2913202 | 16MB Flash + 8MB Octal PSRAM
U3 | 级转换 4通道 | 74AHCT125 | SOIC-14 | 1 | C6082 | 3.3V→5V 风扇PWM电平转换
U4 | 温湿压传感器 | BME280 | LGA-8 | 1 | C92489 | I2C 地址0x76
LED1 | RGB LED | WS2812B-2020 | 2020 | 1 | C2761795 | 3.3V供电 状态指示
F1 | PTC保险丝 | MF-MSMF250-2 2A | SMD-1812 | 1 | C17371 | 12V线路保护
F2 | PTC保险丝 | MF-MSMF100-2 1A | SMD-1812 | 1 | C17370 | 5V线路保护
D1 | 肖特基二极管 | SS34 3A/40V | SMA | 1 | C8678 | 12V防反接
D2 | 肖特基二极管 | SS12 1A/20V | SMA | 1 | C2480 | 5V防反接
D3 | TVS阵列 | SRV05-4 | SOT-363 | 1 | C85972 | USB D+/D- ESD保护
D4 | TVS单向 5.1V | SMAJ5.1A | SMA | 1 | C131405 | Fan1 Tach ESD
D5 | TVS单向 5.1V | SMAJ5.1A | SMA | 1 | C131405 | Fan2 Tach ESD
D6 | TVS单向 5.1V | SMAJ5.1A | SMA | 1 | C131405 | Fan3 Tach ESD
D7 | TVS单向 5.1V | SMAJ5.1A | SMA | 1 | C131405 | Fan4 Tach ESD
D8 | TVS单向 3.6V | SMAJ3.6A | SMA | 1 | C8520 | DS18B20 DQ ESD
J1 | SATA 15Pin | SATA-15P-STRAIGHT | SATA_PWR | 1 |  | SATA电源输入 直插式
J2 | Type-C USB | USB-C-16P | SMD-16P | 1 | C165948 | 数据+编程接口
J3 | 4Pin风扇座 | FAN-4PIN-2.54 | THT-4P | 1 |  | Fan1 PWM风扇接口
J4 | 4Pin风扇座 | FAN-4PIN-2.54 | THT-4P | 1 |  | Fan2 PWM风扇接口
J5 | 4Pin风扇座 | FAN-4PIN-2.54 | THT-4P | 1 |  | Fan3 PWM风扇接口
J6 | 4Pin风扇座 | FAN-4PIN-2.54 | THT-4P | 1 |  | Fan4 PWM风扇接口
J7 | 3Pin接线端子 | KF2510-3P | XH2.54-3P | 1 |  | DS18B20探头接口1
J8 | 3Pin接线端子 | KF2510-3P | XH2.54-3P | 1 |  | DS18B20探头接口2
SW1 | 轻触按键 | 6×6×5mm | THT-4P | 1 | C318884 | 复位按键 (EN)
SW2 | 轻触按键 | 6×6×5mm | THT-4P | 1 | C318884 | Boot模式按键 (IO0)
SW3 | 轻触按键 | 6×6×5mm | THT-4P | 1 | C318884 | WiFi配网按键 (GPIO38)
R1 | 电阻 10kΩ | 10K ±1% | 0805 | 1 | C17414 | EN上拉
R2 | 电阻 10kΩ | 10K ±1% | 0805 | 1 | C17414 | IO0上拉
R3 | 电阻 5.1kΩ | 5K1 ±1% | 0805 | 1 | C23186 | USB CC1下拉
R4 | 电阻 5.1kΩ | 5K1 ±1% | 0805 | 1 | C23186 | USB CC2下拉
R5 | 电阻 100kΩ | 100K ±1% | 0805 | 1 | C17516 | VBUS分压上
R6 | 电阻 10kΩ | 10K ±1% | 0805 | 1 | C17414 | VBUS分压下
R7 | 电阻 100kΩ | 100K ±1% | 0805 | 1 | C17516 | 12V ADC分压上 (修正版)
R8 | 电阻 20kΩ | 20K ±1% | 0805 | 1 | C17431 | 12V ADC分压下 → Vout=2.0V @12V
R9 | 电阻 10kΩ | 10K ±1% | 0805 | 1 | C17414 | 5V ADC分压上
R10 | 电阻 10kΩ | 10K ±1% | 0805 | 1 | C17414 | 5V ADC分压下
R11 | 电阻 10kΩ | 10K ±1% | 0805 | 1 | C17414 | 3.3V ADC分压上
R12 | 电阻 10kΩ | 10K ±1% | 0805 | 1 | C17414 | 3.3V ADC分压下
R13 | 电阻 10kΩ | 10K ±1% | 0805 | 1 | C17414 | Fan1 Tach 5V上拉
R14 | 电阻 2.2kΩ | 2K2 ±1% | 0805 | 1 | C17520 | Fan1 Tach分压上
R15 | 电阻 3.3kΩ | 3K3 ±1% | 0805 | 1 | C17521 | Fan1 Tach分压下
R16 | 电阻 10kΩ | 10K ±1% | 0805 | 1 | C17414 | Fan2 Tach 5V上拉
R17 | 电阻 2.2kΩ | 2K2 ±1% | 0805 | 1 | C17520 | Fan2 Tach分压上
R18 | 电阻 3.3kΩ | 3K3 ±1% | 0805 | 1 | C17521 | Fan2 Tach分压下
R19 | 电阻 10kΩ | 10K ±1% | 0805 | 1 | C17414 | Fan3 Tach 5V上拉
R20 | 电阻 2.2kΩ | 2K2 ±1% | 0805 | 1 | C17520 | Fan3 Tach分压上
R21 | 电阻 3.3kΩ | 3K3 ±1% | 0805 | 1 | C17521 | Fan3 Tach分压下
R22 | 电阻 10kΩ | 10K ±1% | 0805 | 1 | C17414 | Fan4 Tach 5V上拉
R23 | 电阻 2.2kΩ | 2K2 ±1% | 0805 | 1 | C17520 | Fan4 Tach分压上
R24 | 电阻 3.3kΩ | 3K3 ±1% | 0805 | 1 | C17521 | Fan4 Tach分压下
R25 | 电阻 4.7kΩ | 4K7 ±5% | 0805 | 1 | C23162 | I2C SDA上拉
R26 | 电阻 4.7kΩ | 4K7 ±5% | 0805 | 1 | C23162 | I2C SCL上拉
R27 | 电阻 4.7kΩ | 4K7 ±5% | 0805 | 1 | C23162 | 1-Wire DQ上拉
C1 | 电解电容 100uF | 100uF/25V | THT-5mm | 1 | C438663 | 5V LDO输入去耦
C2 | 陶瓷电容 100nF | 100nF/25V | 0805 | 1 | C49678 | 5V LDO输入旁路
C3 | 电解电容 100uF | 100uF/10V | THT-5mm | 1 | C62932 | 3.3V LDO输出去耦
C4 | 陶瓷电容 100nF | 100nF/25V | 0805 | 1 | C49678 | 3.3V LDO输出旁路
C5 | 电解电容 100uF | 100uF/16V | THT-5mm | 1 | C62933 | 5V主线去耦
C6 | 陶瓷电容 100nF | 100nF/25V | 0805 | 1 | C49678 | 5V主线旁路
C7 | 电解电容 470uF | 470uF/25V | THT-8mm | 1 | C60183 | 12V断电保护大电容
C8 | 电解电容 100uF | 100uF/25V | THT-5mm | 1 | C438663 | 12V主线去耦
C9 | 陶瓷电容 100nF | 100nF/25V | 0805 | 1 | C49678 | 12V主线旁路
C10 | 陶瓷电容 100nF | 100nF/25V | 0402 | 1 | C307331 | ESP32 VDD去耦1
C11 | 陶瓷电容 100nF | 100nF/25V | 0402 | 1 | C307331 | ESP32 RTC去耦
C12 | 陶瓷电容 100nF | 100nF/25V | 0402 | 1 | C307331 | ESP32 CPU去耦
C13 | 陶瓷电容 10uF | 10uF/10V | 0805 | 1 | C15850 | ESP32 大容量并联
C14 | 陶瓷电容 100nF | 100nF/25V | 0805 | 1 | C49678 | EN延时电容
C15 | 陶瓷电容 100nF | 100nF/25V | 0805 | 1 | C49678 | 12V ADC采样滤波
C16 | 陶瓷电容 100nF | 100nF/25V | 0805 | 1 | C49678 | 5V ADC采样滤波
C17 | 陶瓷电容 100nF | 100nF/25V | 0805 | 1 | C49678 | 3.3V ADC采样滤波
C18 | 陶瓷电容 100nF | 100nF/25V | 0402 | 1 | C307331 | 74AHCT125去耦
C19 | 电解电容 100uF | 100uF/25V | THT-5mm | 1 | C438663 | Fan1 12V去耦
C20 | 电解电容 100uF | 100uF/25V | THT-5mm | 1 | C438663 | Fan2 12V去耦
C21 | 电解电容 100uF | 100uF/25V | THT-5mm | 1 | C438663 | Fan3 12V去耦
C22 | 电解电容 100uF | 100uF/25V | THT-5mm | 1 | C438663 | Fan4 12V去耦
C23 | 陶瓷电容 100nF | 100nF/25V | 0402 | 1 | C307331 | BME280去耦
C24 | 陶瓷电容 100nF | 100nF/25V | 0402 | 1 | C307331 | WS2812B去耦
C25 | 陶瓷电容 100nF | 100nF/25V | 0805 | 1 | C49678 | 断电检测ADC滤波

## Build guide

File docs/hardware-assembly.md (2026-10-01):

# 硬件组装指南 — Smart Fan Controller v1.2

> 依据：`hardware/docs/remediation-plan-v1.2.md`（v1.2.2）与 `hardware-design-guide-v1.2.md`。
> 位号 v1.2：J1 SATA、J2 USB-C、**J3~J10 八路风扇座**、J11/J12 DS18B20 端子、J13 屏幕排针。

## BOM 采购清单（核心件速查）

| 位号 | 物料 | 规格 | LCSC编号 | 淘宝关键词 | 数量 |
|:----:|---|---|:---:|---|:---:|
| U1 | LDO 3.3V | AMS1117-3.3 SOT-223 | C6186 | AMS1117-3.3 SOT223 | 1 |
| U2 | ESP32-S3 模组 | ESP32-S3-WROOM-1-N16R8 | C2913202 | ESP32-S3 16MB | 1 |
| U3 | 电平转换 | 74AHCT125 SOIC-14 | C6082 | 74AHCT125 贴片 | **2** |
| U4 | 环境传感器 | BME280 LGA-8 | C92489 | BME280 贴片 | 1 |
| U5 | USB ESD | USBLC6-2SC6 SOT-23-6 | C7519 | USBLC6 | 1 |
| LED1 | RGB LED | WS2812B-2020 | C2761795 | WS2812B 2020贴片 | 1 |
| D1 | 肖特基 | SS34 SMA | C8678 | SS34 | 1 |
| D2,D3 | 肖特基 | B5819W SOD-123 | C8598 | B5819W | 2 |
| F1 | 保险丝 12V | **hold ≥3A** PTC（MF-MSMF300-2 或等效） | 下单前确认 | PTC自恢复 3A 1812 | 1 |
| F2 | 保险丝 5V | MF-MSMF100 SMD1812 | C17370 | PTC自恢复保险丝 1A | 1 |
| J1 | SATA 15Pin | 15P电源座直插 | C388659 | SATA电源座15P | 1 |
| J2 | Type-C USB | 16P贴片 | C165948 | Type-C 16P SMD | 1 |
| J3~J10 | 4Pin风扇座 | 2.54mm间距 THT | C86501 | 4pin风扇连接器 | **8** |
| J11,J12 | DS18B20端子 | XH2.54 3P THT | — | XH2.54 3P卧式 | 2 |
| J13 | 屏幕排针 | 2.54mm 8P THT | C92410 | 2.54排针 8P | 1 |
| SW1-SW3 | 轻触按键 | 6×6×5mm | C318884 | 6×6轻触开关 | 3 |

阻容概数（0805）：10kΩ×29、47kΩ×2、100kΩ×1、20kΩ×1、4.7kΩ×3、5.1kΩ×2、33~100Ω×1（WS2812 串阻）、
1nF×8（Tach 滤波）、100nF≥26、10µF×5（12V 轨旁必须 **≥25V** 耐压）、100µF/16V×2、470µF×1。

**完整 BOM**：`hardware/docs/bom-main-board-v1.2.md` + `hardware/BOM.csv`
（**H-06 待原理图完成后生成/重写**——当前两者仍是旧口径，配单前必须等 BOM v1.2 定稿，勿用归档的旧 BOM）。

---

## 焊接工具准备

- 电烙铁（推荐: 白光T12, 330°C）
- 63/37 焊锡丝（0.8mm）
- 助焊剂（松香膏）
- 镊子（直/弯各一把）
- 热风枪（贴片IC可选）
- 放大镜或显微镜（BME280 LGA封装必需）
- 万用表（验证供电）

---

## 焊接顺序

### ⚠️ 关键提示

- **先测后焊**：每步完成后用万用表检查短路（12V→GND, 5V→GND, 3.3V→GND 均应无导通）
- **静电防护**：焊接 ESP32-S3 前佩戴防静电腕带
- **BME280**：LGA封装推荐热风枪回流焊，手焊难度极高

---

### Step 1：电源区焊接（最先验证供电）

1. 焊接 **SATA J1** 连接器
2. 焊接 **F1（≥3A PTC）, F2（1A PTC）**
3. 焊接 **D1（SS34，12V 防反）、D2/D3（B5819W ×2，5V 与 VBUS 支路二极管或）**——注意阳极/阴极方向，阴极朝负载侧
4. 焊接 **U1 AMS1117-3.3**（SOT-223，散热焊盘必须焊牢）
5. 焊接所有电源去耦电容（含 12V 轨旁 10µF——注意 **≥25V 耐压**方向）
6. **测试**：接SATA电源，测量焊盘：
   - 5V轨 → 5.0±0.25V ✓
   - 3.3V轨 → 3.3±0.1V ✓
   - 12V轨 → 12V±10% ✓
   - 所有GND间无短路 ✓

### Step 2：USB 接口与 ESD

1. 焊接 **J2 Type-C**（先对齐再点焊4个角固定）
2. 焊接 **R3, R4**（5.1kΩ CC下拉，紧邻Type-C CC引脚）
3. 焊接 **U5 USBLC6-2SC6**（SOT-23-6，**注意 Pin5 VCC 接的是 +5V 轨**——原理图勿接 3.3V）
4. **测试**：接USB，电脑识别串口 `/dev/ttyACM0` ✓

### Step 3：ESP32-S3 核心

1. 焊接 **SW1（RST）、SW2（BOOT）、SW3（WiFi 配网）**
2. 焊接 **R1, R2**（EN/GPIO0 上拉10kΩ）、**C_EN**（EN 去抖100nF）、**R_CS**（GPIO44 上拉10kΩ）
3. 焊接 **U2 ESP32-S3-WROOM-1**（模块焊盘间距1mm，逐点焊接，避免连锡）
4. 焊接 ESP32 去耦电容（≥8 只 100nF 分布 VDD 引脚周围）
5. **测试**：接USB 重新枚举，`idf.py flash` 可识别芯片（下载模式：按住 SW2 再按 SW1 复位）

### Step 4：风扇驱动电路（8 路）

1. 焊接 **U3 74AHCT125 ×2**（SOIC-14，注意方向标记；两片的 8 个 OE 脚在原理图中均接 GND）
2. 焊接两片的 100nF 去耦电容
3. 焊接 **PWM 下拉电阻 10kΩ ×8**（GPIO5~12 每路一只，接 GND）
4. 焊接 Tach 网络（每路 3 电阻 + 1 电容）：上拉 10kΩ×8（到 +5V）、串联 10kΩ×8、下拉 10kΩ×8、1nF×8
5. 焊接 **J3~J10**（4Pin风扇座 ×8，对齐方向：Pin1=GND 朝丝印标注）
6. 焊接风扇 12V 去耦电容 100nF ×8

### Step 5：传感器和 I/O

1. 焊接 **U4 BME280**（推荐热风枪回流：涂锡膏→放置芯片→300°C热风）
2. 焊接 I²C 上拉电阻 **4.7kΩ ×2**
3. 焊接 **J11, J12**（DS18B20 接线端子）
4. 焊接 OneWire 上拉 **4.7kΩ ×1**
5. 焊接 **LED1 WS2812B-2020**（注意芯片切角方向）+ DIN 串联电阻（33~100Ω）
6. 焊接 **J13**（屏幕排针 8P）

### Step 6：电压监控网络

1. 焊接 12V 分压：**100kΩ + 20kΩ**（±1% 精度，接 GPIO1）
2. 焊接 5V / 3.3V 分压：**47kΩ + 10kΩ ×2**（接 GPIO2 / GPIO4）
3. 焊接 ADC 滤波电容

---

## 上电前检查清单

- [ ] SATA Pin1-3（PWDIS/3.3V）**未连接**（NC，确认）
- [ ] 12V, 5V, 3.3V 轨对 GND 无短路（万用表蜂鸣档）
- [ ] AMS1117 散热焊盘焊牢（对3.3V轨稳定性关键）
- [ ] Type-C CC1/CC2 各有5.1kΩ下拉（USB供电识别）
- [ ] USBLC6 Pin5 接 +5V（非 3.3V）
- [ ] 74AHCT125 两片 8 个 OE 脚全部接地、8 路 PWM 下拉电阻在位
- [ ] ESP32 天线方向朝向板边空旷处（15×15mm 禁布区内无铜/无件）
- [ ] BME280 所有焊盘导通（万用表量芯片引脚对焊盘）
- [ ] WS2812B 方向正确（切角对应GND引脚）

---

## 风扇连接说明

4Pin PWM 风扇标准接法（Intel规范）：

```
Pin1 ─── GND    （黑色线）
Pin2 ─── 12V    （黄色线）
Pin3 ─── TACH   （绿色线，开漏输出）
Pin4 ─── PWM    （蓝色线，5V逻辑输入）
```

⚠️ 不同品牌风扇颜色定义可能不同，**以Pin编号为准**，不以颜色为准。
购买前确认风扇为 4Pin PWM 规格（非3Pin / DC调速）。

**扩展板接入（D1）**：12 路风扇扩展板为成品、独立 SATA 供电，接任意一路 4Pin 风扇座
（建议 Fan8/J10）即可作为普通风扇通道使用，主控板无需任何额外接线和配置。

---

## DS18B20 探头接线

```
探头 Pin1 ─── GND
探头 Pin2 ─── DATA  →  J11/J12 DQ 端子
探头 Pin3 ─── VCC   →  J11/J12 VCC 端子（3.3V）
```

两个探头（J11, J12）共用同一 OneWire 总线（GPIO16），固件按 ROM 地址自动识别并上报。

---

## SATA 电源接口注意事项

本板使用 SATA 15Pin 供电（从服务器电源的 SATA 输出接入）：

- **Pin 7-9**：5V 输出 → 经 D2 与 USB VBUS（经 D3）二极管或后进 +5V 轨 → AMS1117-3.3
- **Pin 13-15**：12V 输出 → 经 F1（≥3A）+ D1 → 直供 8 路风扇
- **Pin 1-3**：`⚠️ 不连接`（PWDIS/3.3V，本板不使用）

推荐使用 15cm 左右的 SATA 延长线，连接服务器电源模组空余接口。
单独 USB 供电时板卡可工作（调试场景），SATA 供电时 USB 仅作数据（D4 决策）。

---

## 测试程序烧录（验收测试）

组装完成后，烧录固件并通过 USB-CDC 串口验证：

```bash
# 烧录固件
idf.py -p /dev/ttyACM0 flash

# 打开串口
screen /dev/ttyACM0 115200

# 发送验收命令（与固件 FW-22 命令集一致）
> status
{"ok":true,"wifi":false,"mqtt":false,"uptime_s":5,"free_heap":285000,"alert_level":0}

> fan 0 50
{"ok":true,"fan":0,"duty":50}
# 此时 Fan1 应能听到转速变化

> wifi status
{"ok":true,"connected":false,"mode_hint":"long-press BTN(GPIO47) 3s = AP provisioning, 10s = factory reset"}

> help
{"ok":true,"data":{"commands":["help","reboot","status","ota","fan","wifi","mqtt"]}}
```

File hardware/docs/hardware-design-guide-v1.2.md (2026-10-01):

# 硬件设计完整指南 v1.2 — 嘉立创EDA版

> **设计依据**：本指南与 `remediation-plan-v1.2.md`（v1.2.2）配套使用；GPIO 分配、电源架构、
> 电路规范以计划的 §0~§3 为唯一权威，本指南为施工镜像。与旧 v1.1 文档冲突时一律以
> 计划与本指南为准。旧 v1.1 指南与 BOM 已归档 `hardware/legacy/docs/`（仅供参考，禁止作为底稿）。

---

## 📐 系统架构

```
┌─────────────────────────────────────────────────────────────────┐
│                         主控板 (v1.2)                             │
│  ESP32-S3-N16R8 + SATA供电                                       │
│  ├─ 8路独立PWM风扇控制 (25 kHz, LEDC 8通道全用)                   │
│  ├─ 8路Tach转速反馈 (PCNT 4单元×2通道全用)                        │
│  ├─ BME280 环境传感器 + 2× DS18B20 探头                          │
│  ├─ 12V/5V/3.3V 电源监控 (ADC1: GPIO1/2/4)                       │
│  ├─ WS2812B RGB LED 状态指示 (GPIO45, RMT)                       │
│  ├─ USB-C 原生USB (编程+console+数据, GPIO19/20)                 │
│  └─ 屏幕接口预留 J13 (SPI 4线 + I2C, UART0 让渡)                 │
└─────────────────────────────────────────────────────────────────┘
              │
              ├─ Fan1~7 (J3~J9):  独立 4Pin 风扇
              └─ Fan8 (J10):      接 12 路扩展板（成品，独立 SATA 供电）

总风扇数: 7 独立 + 12 统一 = 19
扩展板（D1 决策）: 用户自购成品板，独立 SATA 供电，接任意一路 4Pin 座即原生可用
（建议 Fan8/J10）；主控板不做任何扩展板专用电路或固件逻辑。
```

---

## 🔄 v1.1 → v1.2 关键变更

| 项目 | v1.2 现行方案 | 说明 |
|---|---|---|
| **风扇路数** | 8 路独立 | LEDC 8 通道 / PCNT 4×2 通道 / 74AHCT125×2（8 缓冲）三资源同时用满（D2） |
| **板卡规格** | 99×99mm、4 层 | 嘉立创免费打样档（D3）；L1 信号 / L2 完整 GND / L3 电源 / L4 信号 |
| **ADC 引脚** | GPIO1/2/4 | 旧方案的引脚在 N16R8 上不可用（PSRAM 冲突/非 ADC 引脚），作废 |
| **扩展板** | 无专用电路 | D1：成品板独立供电，接一路风扇座；删除全部扩展板专用信号/供电/固件逻辑 |
| **F1 选型** | hold ≥3A PTC | 8 风扇 ≈2.4~2.8A 稳态+浪涌，2.5A hold 会误跳 |
| **USB VBUS** | D3 与 SATA 5V 二极管或 | 防倒灌（D4 决策）；USBLC6 VCC 改接 +5V（H-08） |
| **PWM 下拉** | 10kΩ×8 | 上电窗口期防风扇满转（H-17/MA-19，与固件 FW-13 双保险） |
| **UART0** | 让渡屏幕 SPI | GPIO43/44 → J13；GPIO44 加 10k 上拉（D5/H-12）；console 走 USB |
| **WS2812** | GPIO45 | 旧 GPIO48 让渡屏幕 SPI（D5）；GPIO45 为 strapping(VDD_SPI)，安全 |

---

## 📦 元件清单概览（主控板 v1.2）

> 完整 BOM 以 `bom-main-board-v1.2.md`（H-06，原理图完成后定稿）与 `hardware/BOM.csv` 为准，
> 本表仅为核心元件速查。**旧 BOM（v1.1）已归档 legacy/，禁止用于配单。**

### 核心 IC 与分立元件

| 位号 | 元件 | 型号 | 封装 | 数量 | LCSC 编号 | 备注 |
|:----:|---|---|---|:---:|:---:|---|
| **U1** | LDO 稳压器 | AMS1117-3.3 | SOT-223 | 1 | C6186 | 5V→3.3V；备选 AZ1117-3.3（H-13） |
| **U2** | ESP32 模组 | ESP32-S3-WROOM-1-N16R8 | SMD 18×25.5mm | 1 | C2913202 | 天线朝板边/板外悬空 |
| **U3** | 电平转换 | 74AHCT125D | SOIC-14 | **2** | C6082 | 8 通道全用，OE 全接地 |
| **U4** | 环境传感器 | BME280 | LGA-8 | 1 | C92489 | I2C 0x76 |
| **U5** | ESD 保护 | USBLC6-2SC6 | SOT-23-6 | 1 | C7519 | **VCC 接 +5V 轨**（H-08，勿接 3.3V） |
| **LED1** | RGB LED | WS2812B-2020 | 2020 | 1 | C2761795 | 3.3V 供电 |
| **D1** | 肖特基 | SS34 | SMA | 1 | C8678 | 12V 防反接 |
| **D2** | 肖特基 | B5819W | SOD-123 | 1 | C8598 | SATA 5V 支路 |
| **D3** | 肖特基 | B5819W | SOD-123 | 1 | C8598 | USB VBUS→+5V 二极管或（H-05） |
| **F1** | PTC 保险丝 | MF-MSMF300-2 或基础库等效 | 1812 | 1 | 下单前确认 | **hold ≥3A**（12V 支路） |
| **F2** | PTC 保险丝 | MF-MSMF100 | 1812 | 1 | C17370 | 1A（5V 支路） |
| **F3** | PTC 保险丝 | 1A（可选） | 1812 | 0~1 | — | VBUS 支路，NC 亦可（位号预留） |

### 连接器（v1.2 位号）

| 位号 | 元件 | 规格 | 封装 | 数量 | LCSC 编号 | 备注 |
|:----:|---|---|---|:---:|:---:|---|
| **J1** | SATA 电源座 | 15P 直插 | THT | 1 | C388659 | Pin1-3（3.3V/PWDIS）不连 |
| **J2** | USB-C 座 | 16P 贴片 | SMD | 1 | C165948 | 差分紧邻 U5 |
| **J3~J10** | 风扇座 | 4Pin 2.54 | THT | **8** | C86501 | Fan1~Fan8 |
| **J11/J12** | DS18B20 端子 | XH2.54 3P | THT | 2 | — | 两探头共用 DQ 总线 |
| **J13** | 屏幕接口 | 2.54 排针 8P | THT | 1 | C92410 | Pin5=SPI_CS 带 10k 上拉 |

### 阻容器件（概数，以 BOM 定稿为准）

| 类型 | 规格 | 封装 | 数量 | 用途 |
|---|---|---|:---:|---|
| 电阻 | 10kΩ ±1% | 0805 | 29 | EN/GPIO0 上拉×2、GPIO44 CS 上拉×1、Tach 上拉/串联/下拉 8×3、PWM 下拉×8（H-17）、5V/3V3 分压下臂×2 |
| 电阻 | 20kΩ ±1% | 0805 | 1 | 12V 分压下臂（÷6） |
| 电阻 | 47kΩ ±1% | 0805 | 2 | 5V/3.3V 分压上臂（÷5.7） |
| 电阻 | 100kΩ ±1% | 0805 | 1 | 12V 分压上臂 |
| 电阻 | 4.7kΩ ±1% | 0805 | 3 | I2C ×2 + OneWire ×1 上拉 |
| 电阻 | 5.1kΩ ±1% | 0805 | 2 | USB CC 下拉 |
| 电阻 | 33~100Ω | 0805 | 1 | WS2812 DIN 串阻（H-14） |
| 电容 | 1nF | 0805 | 8 | Tach 滤波（每路 1 只） |
| 电容 | 100nF | 0805 | ≥26 | ESP32 ≥8 + 74AHCT125×2 + 传感器/LED/USB + 风扇座 12V 去耦×8 + EN 去抖 |
| 电容 | 10µF | **16V/25V** | 5 | 12V 轨旁的必须 ≥25V（H-06 修订） |
| 电容 | 100µF | 直插，≥16V | 2 | 12V 断电保持 |
| 电容 | 470µF | 直插 8×12 | 1 | 5V 滤波 |

按键：SW1(RST/EN)、SW2(BOOT/GPIO0)、SW3(WiFi 配网/GPIO47)，6×6×5mm，C318884。安装孔 M3 ×4。

---

## 🔌 GPIO 分配总表（唯一权威 = remediation-plan-v1.2.md §1）

| GPIO | 网络名 | 方向 | 外设资源 | 备注 |
|:----:|---|:----:|---|---|
| EN | RESET | IN | — | 10kΩ 上拉 + 100nF 去抖 + SW1 接地 |
| GPIO0 | BOOT | IN | strapping | 10kΩ 上拉 + SW2 接地 |
| GPIO1 | ADC_12V | IN | ADC1_CH0 | 100k/20k 分压（÷6） |
| GPIO2 | ADC_5V | IN | ADC1_CH1 | 47k/10k 分压（÷5.7） |
| GPIO3 | **NC** | — | strapping | JTAG 源选择，禁止外接任何负载 |
| GPIO4 | ADC_3V3 | IN | ADC1_CH3 | 47k/10k 分压（÷5.7） |
| GPIO5 | FAN1_PWM | OUT | LEDC_CH0 | → 74AHCT125 #1 |
| GPIO6 | FAN2_PWM | OUT | LEDC_CH1 | → 74AHCT125 #1 |
| GPIO7 | FAN3_PWM | OUT | LEDC_CH2 | → 74AHCT125 #1 |
| GPIO8 | FAN4_PWM | OUT | LEDC_CH3 | → 74AHCT125 #1 |
| GPIO9 | FAN5_PWM | OUT | LEDC_CH4 | → 74AHCT125 #2 |
| GPIO10 | FAN6_PWM | OUT | LEDC_CH5 | → 74AHCT125 #2，建议接扩展板 |
| GPIO11 | FAN7_PWM | OUT | LEDC_CH6 | → 74AHCT125 #2 |
| GPIO12 | FAN8_PWM | OUT | LEDC_CH7 | → 74AHCT125 #2 |
| GPIO13 | FAN1_TACH | IN | PCNT_U0_CH0 | 分压输入（见 Tach 网络） |
| GPIO14 | FAN2_TACH | IN | PCNT_U0_CH1 | |
| GPIO15 | FAN3_TACH | IN | PCNT_U1_CH0 | |
| GPIO16 | DS18B20_DQ | I/O | OneWire | 4.7kΩ 上拉，J11/J12 共用 |
| GPIO17 | I2C_SDA | I/O | I2C0_SDA | 4.7kΩ 上拉，BME280 + 屏幕 |
| GPIO18 | I2C_SCL | OUT | I2C0_SCL | 4.7kΩ 上拉 |
| GPIO19 | USB_D- | I/O | USB | 原生 USB |
| GPIO20 | USB_D+ | I/O | USB | 原生 USB |
| GPIO21 | FAN4_TACH | IN | PCNT_U1_CH1 | |
| GPIO38 | FAN5_TACH | IN | PCNT_U2_CH0 | |
| GPIO39 | FAN6_TACH | IN | PCNT_U2_CH1 | MTCK，正常 GPIO 使用 |
| GPIO40 | FAN7_TACH | IN | PCNT_U3_CH0 | |
| GPIO41 | FAN8_TACH | IN | PCNT_U3_CH1 | |
| GPIO42 | SPI_SCK | OUT | GPIO 矩阵 | 屏幕 J13 Pin3 |
| GPIO43 | SPI_MOSI | OUT | GPIO 矩阵 | 屏幕 J13 Pin4（原 UART0_TX） |
| GPIO44 | SPI_CS | OUT | GPIO 矩阵 | 屏幕 J13 Pin5，**10kΩ 上拉到 3.3V**（防上电 UART0 日志串入） |
| GPIO45 | WS2812B_DI | OUT | RMT | strapping(VDD_SPI)：DIN 高阻+内部下拉，安全 |
| GPIO46 | **NC** | — | strapping | boot 模式选择，禁止外接负载 |
| GPIO47 | BTN_WIFI_CFG | IN | GPIO 输入 | 10kΩ 上拉 + SW3 接地 |
| GPIO48 | SPI_DC | OUT | GPIO 矩阵 | 屏幕 J13 Pin6 |

**禁用引脚（必须写进原理图注释）：**
- GPIO26~32：模组内 SPI Flash 占用，WROOM-1 未引出。
- GPIO35~37：N16R8 八线 PSRAM 占用，**不可用**；原理图符号上标注 NC。GPIO33/34 模组未引出。
- Strapping 引脚（GPIO0/3/45/46）：除本表指定用法外禁止外接负载。

风扇索引约定：文档写 Fan1~Fan8，固件/协议用 index 0~7（Fan1 = index 0）。

---

## ⚡ 电源架构 v1.2

```
SATA 12V (Pin13-15) → F1 [PTC, hold ≥3A] → D1 [SS34] → +12V 轨
    +12V 轨 → J3~J10 Pin2（8 路风扇，每路 100nF 去耦）
    +12V 轨 → 100k/20k 分压 → GPIO1

SATA 5V (Pin7-9) → F2 [PTC 1A] → D2 [B5819W] ──┐
USB-C VBUS       → D3 [B5819W] ────────────────┴→ +5V 轨
    +5V 轨 → AMS1117-3.3 → +3V3（10µF+100nF 输出，≥8×100nF ESP32 去耦）
    +5V 轨 → 74AHCT125 #1/#2 VCC（各 100nF 去耦）
    +5V 轨 → 8 路 Tach 上拉（10kΩ×8）
    +5V 轨 → USBLC6 VCC（H-08）
    +3V3 → ESP32 / BME280 / WS2812B / DS18B20 / 全部上拉与分压下臂
```

要点：
- F1 hold ≥3A：8 风扇 ≈2.4~2.8A 稳态 + 启动浪涌；2.5A hold 会误跳（原 MF-MSMF250 作废）。
- 12V 载流按 IPC-2150：1oz 外层 2mm 走线仅约 4A（10℃ 温升）——**旧文档"2.0mm=6A"表述错误已废除**。
  4 层板中 12V 在 L3 铺铜（≥5mm 宽或区块铺铜），过孔阵列换层（H-10）。
- SATA Pin1-3（3.3V/PWDIS）不连接。
- USB VBUS 支路可加可选 1A PTC（F3，NC 亦可）。

---

## 🔧 关键电路规范（原理图绘制按此执行）

### Tach 输入网络（每路 3 电阻 + 1 电容，共 8 组）

```
风扇 Pin3(Tach, 开漏) ──[10kΩ 上拉至 +5V]──┬──[10kΩ 串联]──┬──→ GPIO
                                            │                │
                                          (节点)          [10kΩ 下拉至 GND] + [1nF 至 GND]
高电平 = 5V × 10k/(10k+10k) = 2.5V > VIH 2.31V ✓
```
共需 10kΩ×24 + 1nF×8。**Tach 必须上拉到 5V**（开漏输出，拉 3.3V 无信号）。

### 74AHCT125（2 片，SOIC-14）

- #1：GPIO5~8 → FAN1~4_PWM；#2：GPIO9~12 → FAN5~8_PWM。8 通道全用，无悬空通道。
- 两片 OE1~OE4（Pin1/4/10/13）**全部接 GND**，原理图明确画出。
- VCC=+5V，各配 100nF 去耦。
- **每路 A 输入线（GPIO5~12 PWM 网络）加 10kΩ 下拉到 GND，共 8 只（H-17）**：上电窗口期
  ESP32 引脚高阻、OE 恒使能，无下拉则缓冲输出不定、风扇可能满转数百毫秒。

### USB-C（J2）+ ESD

- CC1/CC2 各 5.1kΩ 下拉；A6/A7 与 B6/B7 并联。
- **USBLC6-2SC6 的 VCC（Pin5）接 +5V 轨**（H-08 修正：按 5V 供电设计，接 3.3V 钳位行为不正确）。
- D± 差分 90Ω、等长误差 ≤5mm、紧邻 J2 放置。
- VBUS 经 D3（B5819W）进 +5V 轨，与 SATA 5V 支路 D2 构成二极管或，杜绝倒灌（H-05）。

### BME280 / DS18B20 / WS2812B

- BME280：I2C 0x76，SDO→GND、CSB→3.3V，SDA/SCL 4.7kΩ 上拉，100nF 去耦。
- DS18B20：GPIO16 OneWire，4.7kΩ 上拉，J11/J12 两探头共用总线。**不支持寄生供电模式**（固件
  bit-bang 驱动按外部供电设计）。
- WS2812B：GPIO45（RMT），DIN 串 33~100Ω（H-14），3.3V 供电（VIH_min=2.31V < VOH 3.0V ✓），
  100nF 去耦，DOUT 悬空。

### ADC 分压网络

| 网络 | GPIO | 上臂 | 下臂 | 分压比 | 满量程电压 |
|---|:----:|---|---|:---:|---|
| ADC_12V | GPIO1 (ADC1_CH0) | 100kΩ | 20kΩ | ÷6 | 12V→2.0V |
| ADC_5V | GPIO2 (ADC1_CH1) | 47kΩ | 10kΩ | ÷5.7 | 5V→0.88V |
| ADC_3V3 | GPIO4 (ADC1_CH3) | 47kΩ | 10kΩ | ÷5.7 | 3.3V→0.58V |

全部 ≤2.0V，低于 ADC 安全区上限。旧审查清单"47k+18k"矛盾表述已删除。

### 屏幕接口 J13（2.54 排针 8P）

Pin1=3.3V，Pin2=GND，Pin3=SPI_SCK(GPIO42)，Pin4=SPI_MOSI(GPIO43)，Pin5=SPI_CS(GPIO44，带 10k 上拉)，
Pin6=SPI_DC(GPIO48)，Pin7=I2C_SDA(GPIO17)，Pin8=I2C_SCL(GPIO18)。

---

## 📏 PCB 设计约束（99×99mm 4 层，D3）

### 叠层

L1 信号+元件 / **L2 完整 GND（无分割）** / L3 电源（12V 铺铜 + 5V/3.3V）/ L4 信号。

### 工艺（嘉立创免费档）

| 参数 | 规格 |
|---|---|
| 板框 | 99×99mm（≤100×100 免费档） |
| 层数 | 4 层（2/4 层均免费，5 片/月 2 券） |
| 板厚 / 铜厚 | 1.6mm / 1oz（标准工艺） |
| 最小线宽/间距 | 0.127mm（设计目标 ≥0.2mm） |
| 过孔 | 0.3mm 孔 / 0.6mm 焊盘 |

### 走线规则（IPC-2150 口径）

| 网络类 | 电流 | 方案 | 备注 |
|---|---|---|---|
| **12V** | ≈3A 稳态 | **L3 铺铜**（≥5mm 宽或区块） | 外层 2mm 仅约 4A@10℃ 温升，勿依赖表层走线载 12V |
| 5V | 1A | ≥1.0mm | LDO 输入 |
| 3.3V | 0.5A | ≥0.8mm | ESP32 供电 |
| PWM 信号 | <10mA | 0.25mm | 74AHCT125 输出侧 |
| Tach 信号 | <1mA | 0.25mm | 分压后 |
| USB D± | — | 0.25mm 差分 90Ω | 等长 ≤5mm，紧邻 J2 |
| I2C | <5mA | 0.25mm | SDA/SCL |

### 布局要点

```
[主控板布局 - 顶层俯视 99×99]

    ┌─────────────────────────────────────────┐
    │ [J1 SATA]                   [J2 USB-C]  │
    │                                          │
    │  [U1 LDO] ← (散热区 ≥4cm²)               │
    │                                          │
    │      [U2 ESP32-S3]  →天线 (15×15 禁布区)→│板边
    │                                          │
    │  [U3 74AHCT125#1]   [U3 74AHCT125#2]     │
    │                                          │
    │  [J3][J4][J5][J6]   ← 风扇接口行1         │
    │  [J7][J8][J9][J10]  ← 风扇接口行2         │
    │                                          │
    │  [J11][J12]   [J13 屏幕]                 │
    │  DS18B20×2                               │
    │                                          │
    │  [SW1][SW2][SW3]   [LED1]                │
    │  RST  BOOT  WIFI    RGB                  │
    │  [M3 安装孔 ×4 四角]                      │
    └─────────────────────────────────────────┘
```

关键约束：
1. **ESP32 天线区**：模组天线端 15×15mm 禁布区（keepout 功能实现，非丝印文字），天线端出板边或悬空。
2. **AMS1117 散热**：GND 铺铜 ≥4cm² + 2mm 间距过孔阵列（H-13）；WiFi 高负载 3.3V 跌落 >5% 时备选 AZ1117-3.3。
3. **去耦电容**：距 IC 电源脚 <5mm。
4. **USB 差分**：D+/D- 等长 ≤5mm，远离时钟源。
5. **12V**：L3 铺铜，过孔阵列换层到风扇座。

---

## 🛠️ 嘉立创 EDA 操作流程（v1.2 工程）

1. **新建工程**：嘉立创 EDA 专业版 → 工程名 `Smart-Fan-Controller-Main-v1.2`，**工程文件存仓库 `hardware/lceda/`**（D6：唯一硬件真源）。
2. **放置元件**：系统库按 LCSC 编号搜索（ESP32-S3-WROOM-1 在嘉立创库有现成符号+封装）。
3. **绘制原理图**：按电源 → ESP32 最小系统 → 8 路 PWM → 8 路 Tach → 传感器 → USB → J13 顺序；网络标签用 `+12V/+5V/+3V3/GND` 电源符号。
4. **ERC 清零**：电气规则检查 0 错误 0 警告；对照 `schematic-review-checklist.md`（v1.2）逐项勾选。
5. **更新 PCB** → 板框 99×99 → 按上述布局要点摆放 → 设定走线规则 → 布线 → L2/L3 覆铜 → DRC 清零。
6. **归档**：可编辑工程 + 原理图 PDF + BOM + Gerber + 钻孔 + ERC/DRC 截图证据 → `hardware/`（BOM 按 H-06 生成 `bom-main-board-v1.2.md` + 重写 `hardware/BOM.csv`）。
7. **下单**：一键下单 → 5 片、1.6mm、1oz、HASL 无铅。

---

## 📐 电气参数计算（速查）

**12V 分压（GPIO1）**：12V × 20k/(100k+20k) = 2.0V ✓；实测 10.8~13.2V → ADC 1.8~2.2V 安全。
软件换算：`V = ADC_raw × (3.3/4095) × 6.0`（5V/3.3V 同理 ×5.7）。

**Tach**：2 脉冲/转，PCNT 1s 窗口，`RPM = count × 60 / 2`；500~3000 RPM → 16.7~100Hz。

**PWM**：LEDC 25kHz（Intel 4Pin 规范），10bit 分辨率。

---

## 📚 附录：配套文档（均为仓库实际存在文件）

- `remediation-plan-v1.2.md` — 硬件整改计划（v1.2.2，唯一权威设计依据）
- `bom-main-board-v1.2.md` — v1.2 BOM（H-06，原理图完成后生成）
- `schematic-review-checklist.md` — 原理图审查清单（v1.2）
- `changelog-v1.2.md` — 硬件整改销号日志
- 旧 v1.1 指南/BOM：`hardware/legacy/docs/`（仅参考）

---

**版本历史：**
- v1.2 (2026-08-26): 8 路 / 99×99 4 层 / GPIO v1.2 权威表 / 二极管或 / PWM 下拉 / F1≥3A / USBLC6+5V；配合整改计划 v1.2.2
- v1.1 (2026-01-30): 旧版（已归档 legacy/，内容作废）
- v1.0 (2026-01-28): 初版（已归档）

**许可：** MIT License

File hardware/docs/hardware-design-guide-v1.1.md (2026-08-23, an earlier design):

# 硬件设计完整指南 — 嘉立创EDA版

## 📐 系统架构

```
┌─────────────────────────────────────────────────────────────────┐
│                         主控板 (v1.1)                             │
│  ESP32-S3-N16R8 + SATA供电                                       │
│  ├─ 6路独立PWM风扇控制 (25 kHz)                                  │
│  ├─ 6路Tach转速反馈 (PCNT硬件计数)                               │
│  ├─ BME280 环境传感器 + 2× DS18B20 探头                         │
│  ├─ 12V/5V/3.3V 电源监控                                         │
│  ├─ WS2812B RGB LED 状态指示                                     │
│  ├─ USB-C 原生CDC (编程+调试)                                    │
│  └─ 屏幕接口预留 (SPI 4线 + I2C)                                │
└─────────────────────────────────────────────────────────────────┘
              │
              ├─ Fan1~5: 普通4Pin风扇 (独立控制)
              │
              └─ Fan6: 外接12路扩展板 (已购买)
                       ↓
                  [12路风扇统一受控]
                  
总计: 5+12 = 17个风扇
```

---

## 🎯 设计目标调整

| 参数 | 原设计 (v1.0) | 新设计 (v1.1) |
|---|---|---|
| **主控板风扇数** | 4路独立 | **6路独立** (其中1路接扩展板) |
| **扩展板** | 无 | **外接已购买的成品板** |
| **屏幕接口** | 无 | **SPI+I2C预留** |
| **PCB尺寸** | 80×60mm | **100×70mm** |
| **供电** | SATA 15Pin | 主控板SATA供电 |
| **通信** | USB-CDC + WiFi | USB-CDC + WiFi + MQTT |

---

## 📦 元件清单 (主控板 v1.1)

### 核心元件 (嘉立创商城可购买)

| 位号 | 元件 | 型号 | 封装 | 数量 | LCSC编号 | 嘉立创型号 | 备注 |
|:----:|---|---|---|:---:|:---:|---|---|
| **U1** | LDO稳压器 | AMS1117-3.3 | SOT-223 | 1 | C6186 | AMS1117-3.3 | 5V→3.3V，散热焊盘 |
| **U2** | ESP32模组 | ESP32-S3-WROOM-1-N16R8 | SMD 18×25.5mm | 1 | C2913202 | ESP32-S3 16MB | 注意天线方向 |
| **U3** | 电平转换 | 74AHCT125D | SOIC-14 | **2** | C6082 | 74AHCT125 | **6路需要2片** |
| **U4** | 环境传感器 | BME280 | LGA-8 | 1 | C92489 | BME280 | I2C地址0x76 |
| **U5** | ESD保护 | USBLC6-2SC6 | SOT-23-6 | 1 | C7519 | USBLC6 | USB D±保护 |
| **LED1** | RGB LED | WS2812B-2020 | 2020 | 1 | C2761795 | WS2812B | 3.3V供电 |
| **D1** | 肖特基二极管 | SS34 | SMA | 1 | C8678 | SS34 | 12V防反接 |
| **D2** | 肖特基二极管 | B5819W | SOD-123 | 1 | C8598 | B5819W | 5V防反接 |
| **F1** | PTC保险丝 | MF-MSMF250 | 1812 | 1 | C17371 | 2A自恢复 | 12V支路 |
| **F2** | PTC保险丝 | MF-MSMF100 | 1812 | 1 | C17370 | 1A自恢复 | 5V支路 |

### 连接器

| 位号 | 元件 | 规格 | 封装 | 数量 | LCSC编号 | 备注 |
|:----:|---|---|---|:---:|:---:|---|
| **J1** | SATA电源座 | 15P直插 | THT | 1 | C388659 | SATA电源输入 |
| **J2** | USB-C座 | 16P贴片 | SMD | 1 | C165948 | Type-C USB |
| **J3~J8** | 风扇座 | 4Pin 2.54间距 | THT | **6** | C86501 | **扩展到6路** |
| **J9,J10** | 接线端子 | XH2.54 3P | THT | 2 | — | DS18B20探头 |
| **J11** | 屏幕接口 | 2.54排针 8P | THT | 1 | C92410 | SPI+I2C预留 |

### 阻容器件 (嘉立创基础库)

| 类型 | 规格 | 封装 | 数量 | 用途 |
|---|---|---|:---:|---|
| **电阻** | 10kΩ ±1% | 0805 | 8 | EN/IO0上拉，I2C上拉 |
| **电阻** | 4.7kΩ ±1% | 0805 | 3 | I2C/OneWire上拉 |
| **电阻** | 5.1kΩ ±1% | 0805 | 2 | USB CC下拉 |
| **电阻** | 100kΩ ±1% | 0805 | 1 | 12V分压上臂 |
| **电阻** | 20kΩ ±1% | 0805 | 1 | 12V分压下臂 |
| **电阻** | 47kΩ ±1% | 0805 | 2 | 5V/3.3V分压上臂 |
| **电阻** | 10kΩ ±1% | 0805 | 2 | 5V/3.3V分压下臂 |
| **电阻** | 10kΩ ±5% | 0805 | **12** | Tach上拉 (**6路×2=12个**) |
| **电容** | 100nF | 0805 | 20 | 去耦电容 |
| **电容** | 10µF | 0805 | 5 | 去耦电容 |
| **电容** | 100µF | 直插6.3×7.7 | 2 | 断电保护 |
| **电容** | 470µF | 直插8×12 | 1 | 5V滤波 |

### 按键与开关

| 位号 | 元件 | 规格 | 封装 | 数量 | LCSC编号 |
|:----:|---|---|---|:---:|:---:|
| **SW1~SW3** | 轻触开关 | 6×6×5mm | THT | 3 | C318884 |

---

## 📦 元件清单 (扩展板 v1.0)

### 简化BOM（无主控）

| 位号 | 元件 | 型号 | 数量 | LCSC编号 | 备注 |
|:----:|---|---|:---:|:---:|---|
| **U1** | LDO稳压器 | AMS1117-5.0 | 1 | C6187 | **12V→5V** (扩展板用) |
| **J1** | SATA电源座 | 15P直插 | 1 | C388659 | 独立供电 |
| **J2** | 航插座 | PH2.0 3P母座 | 1 | C157929 | 接收主控PWM信号 |
| **J3~J14** | 风扇座 | 4Pin 2.54 | **12** | C86501 | **12路风扇** |
| **D1** | 肖特基 | SS34 | 1 | C8678 | 12V防反接 |
| **F1** | PTC保险丝 | MF-MSMF500 | 1 | C101142 | **5A** (12风扇共用) |
| **电阻** | 10kΩ | 0805 | 1 | — | PWM信号上拉 |
| **电容** | 100nF | 0805 | 10 | — | 风扇接口去耦 |
| **电容** | 1000µF | 直插10×20 | 1 | — | 12V大滤波 |

---

## 🔌 接口定义与引脚分配

### ESP32-S3 GPIO分配表 (主控板 v1.1)

| GPIO | 功能 | 方向 | 电平 | 外设 | 备注 |
|:----:|---|:----:|:----:|:----:|---|
| **GPIO1** | Fan1_PWM | OUT | 3.3V | LEDC_CH0 | 74AHCT125转5V |
| **GPIO2** | Fan2_PWM | OUT | 3.3V | LEDC_CH1 | 74AHCT125转5V |
| **GPIO3** | Fan3_PWM | OUT | 3.3V | LEDC_CH2 | 74AHCT125转5V |
| **GPIO4** | Fan4_PWM | OUT | 3.3V | LEDC_CH3 | 74AHCT125转5V |
| **GPIO5** | Fan5_PWM | OUT | 3.3V | LEDC_CH4 | **新增** |
| **GPIO6** | Fan6_PWM | OUT | 3.3V | LEDC_CH5 | **新增** |
| **GPIO7** | Fan1_Tach | IN | 5V→3.3V | PCNT_U0 | 分压输入 |
| **GPIO8** | Fan2_Tach | IN | 5V→3.3V | PCNT_U1 | 分压输入 |
| **GPIO9** | Fan3_Tach | IN | 5V→3.3V | PCNT_U2 | 分压输入 |
| **GPIO10** | Fan4_Tach | IN | 5V→3.3V | PCNT_U3 | 分压输入 |
| **GPIO11** | Fan5_Tach | IN | 5V→3.3V | PCNT_U4 | **新增** |
| **GPIO12** | Fan6_Tach | IN | 5V→3.3V | PCNT_U5 | **新增** |
| **GPIO16** | DS18B20_DQ | I/O | 3.3V | OneWire | 4.7k上拉 |
| **GPIO17** | I2C_SDA | I/O | 3.3V | I2C0_SDA | BME280 + 屏幕 |
| **GPIO18** | I2C_SCL | OUT | 3.3V | I2C0_SCL | BME280 + 屏幕 |
| **GPIO19** | USB_D- | I/O | 3.3V | USB OTG | 原生USB |
| **GPIO20** | USB_D+ | I/O | 3.3V | USB OTG | 原生USB |
| **GPIO21** | ADC_12V | IN | Analog | ADC1_CH0 | 100k+20k分压 |
| **GPIO35** | ADC_5V | IN | Analog | ADC1_CH4 | 47k+10k分压 |
| **GPIO36** | ADC_3V3 | IN | Analog | ADC1_CH5 | 47k+10k分压 |
| **GPIO38** | BTN_WIFI_CFG | IN | 3.3V | Input | 10k上拉 |
| **GPIO39** | SPI_CS | OUT | 3.3V | SPI2_CS | 屏幕片选 (预留) |
| **GPIO40** | SPI_MOSI | OUT | 3.3V | SPI2_MOSI | 屏幕数据 (预留) |
| **GPIO41** | SPI_SCK | OUT | 3.3V | SPI2_SCK | 屏幕时钟 (预留) |
| **GPIO42** | SPI_DC | OUT | 3.3V | GPIO | 屏幕DC (预留) |
| **GPIO48** | WS2812B_DI | OUT | 3.3V | RMT_CH0 | RGB LED数据 |
| **EN** | Reset | IN | 3.3V | - | 10k上拉 + 按键 |
| **GPIO0** | Boot | IN | 3.3V | - | 10k上拉 + 按键 |

---

## 🎨 原理图绘制指南 (嘉立创EDA)

### 模块1：电源电路 (主控板)

```
[SATA J1 Pin7-9 (5V)] 
        ↓
    [F2: PTC 1A]
        ↓
    [D2: B5819W 肖特基] (防反接)
        ↓
    [C1: 470µF] ─┬─ +5V_IN
                 │
                 ├─→ [U1: AMS1117-3.3]
                 │        ↓
                 │    [C2: 10µF] ─┬─ +3V3 (ESP32供电)
                 │                 │
                 │                 └─ [C3~C10: 100nF] (去耦)
                 │
                 └─→ +5V (74AHCT125 供电)

[SATA J1 Pin13-15 (12V)]
        ↓
    [F1: PTC 2A]
        ↓
    [D1: SS34 肖特基]
        ↓
    [C11: 100µF] ─┬─ +12V (风扇供电)
                  │
                  └─→ [分压网络] → ADC_12V (GPIO21)
```

**关键参数：**
- AMS1117-3.3 散热焊盘必须焊接到GND覆铜（≥2cm²）
- 12V走线宽度 ≥ 2.0mm（单面6A）
- 5V走线宽度 ≥ 1.0mm
- 3.3V走线宽度 ≥ 0.8mm

---

### 模块2：74AHCT125 电平转换 (6路PWM)

```
[ESP32 GPIO1~6 (3.3V PWM)]
        ↓
    [74AHCT125 #1]
        Pin1 (1OE) → GND (使能)
        Pin2 (1A)  ← GPIO1
        Pin3 (1Y)  → Fan1_PWM (5V)
        Pin4 (2A)  ← GPIO2
        Pin5 (2Y)  → Fan2_PWM (5V)
        Pin6 (3A)  ← GPIO3
        Pin7 (GND) → GND
        Pin8 (3Y)  → Fan3_PWM (5V)
        Pin9 (4A)  ← GPIO4
        Pin10(4Y)  → Fan4_PWM (5V)
        Pin14(VCC) → +5V
        
    [74AHCT125 #2] (新增)
        Pin2 (1A)  ← GPIO5
        Pin3 (1Y)  → Fan5_PWM (5V)
        Pin5 (2A)  ← GPIO6
        Pin6 (2Y)  → Fan6_PWM (5V)
        Pin9~12 悬空或接地 (未使用)

[去耦电容]
    74AHCT125 #1 Pin14 ─ [100nF] ─ GND
    74AHCT125 #2 Pin14 ─ [100nF] ─ GND
```

---

### 模块3：风扇接口 (单路示意，重复6次)

```
[Fan_J3 (4Pin风扇座)]
    Pin1 (GND)  → GND
    Pin2 (12V)  ← +12V ─ [100nF去耦]
    Pin3 (Tach) → [R: 10k上拉至5V] ┬─ [分压: 10k+10k] → GPIO7 (3.3V)
    Pin4 (PWM)  ← Fan1_PWM (5V)      └─ Tach开漏输出

[分压计算]
    Tach输出: 5V (高) / 0V (低)
    经10k+10k分压: 2.5V (高) / 0V (低)
    符合ESP32 输入要求 (VIH_min=2.31V @ 3.3V_IO)
```

**重要：**
- Tach 必须上拉到 5V（不是 3.3V），否则风扇无法输出信号
- PWM 输入为 5V 逻辑（Intel 4Pin 规范要求 VIH_min=3.8V）
- 每路风扇 12V 引脚并联 100nF 陶瓷电容（去耦）

---

### 模块4：传感器接口

```
[BME280 (U4) - I2C地址0x76]
    Pin1 (SDI/SDA) ← I2C_SDA (GPIO17) ─ [4.7k上拉至3.3V]
    Pin2 (SCK/SCL) ← I2C_SCL (GPIO18) ─ [4.7k上拉至3.3V]
    Pin3 (SDO)     → GND (地址选择: 0x76)
    Pin5 (CSB)     → 3.3V (I2C模式)
    Pin6 (VDD)     ← 3.3V
    Pin7 (VDDIO)   ← 3.3V
    Pin8 (GND)     → GND
    [去耦: Pin6 ─ 100nF ─ GND]

[DS18B20探头 J9/J10 (XH2.54 3P)]
    Pin1 (GND)  → GND
    Pin2 (DQ)   ← DS18B20_DQ (GPIO16) ─ [4.7k上拉至3.3V]
    Pin3 (VCC)  ← 3.3V

[WS2812B LED1 (2020封装)]
    Pin1 (VDD)  ← 3.3V ─ [100nF去耦]
    Pin2 (DOUT) → NC
    Pin3 (GND)  → GND
    Pin4 (DIN)  ← WS2812B_DI (GPIO48)
    
    注意：3.3V供电时 VIH_min=2.31V < ESP32 VOH=3.0V ✅
```

---

### 模块5：USB-C接口

```
[USB-C J2 (16Pin贴片)]
    A1/A12 (GND)       → GND
    A4/A9  (VBUS)      → +5V_USB ─ [10µF ║ 100nF]
    A5     (CC1)       ← [R: 5.1k] → GND (下拉)
    B5     (CC2)       ← [R: 5.1k] → GND (下拉)
    A6     (D+)        ─┬─ [U5: USBLC6 Pin6] ─→ USB_D+ (GPIO20)
    A7     (D-)        ─┼─ [U5: USBLC6 Pin3] ─→ USB_D- (GPIO19)
    B6/B7  (D+/D-)     ─┘  (并联A6/A7)
    
[ESD保护 USBLC6-2SC6 (SOT-23-6)]
    Pin1 (I/O_1) ← D- from J2
    Pin2 (GND)   → GND
    Pin3 (I/O_2) ← D+ from J2
    Pin4 (I/O_2) → D+ to ESP32
    Pin5 (VCC)   ← 3.3V
    Pin6 (I/O_1) → D- to ESP32
```

---

### 模块6：屏幕接口预留 (J11 排针8P)

```
[2.54mm 排针 8P]
    Pin1 → 3.3V         (屏幕供电)
    Pin2 → GND
    Pin3 → SPI_SCK      (GPIO41)
    Pin4 → SPI_MOSI     (GPIO40)
    Pin5 → SPI_CS       (GPIO39)
    Pin6 → SPI_DC       (GPIO42)  (数据/命令选择)
    Pin7 → I2C_SDA      (GPIO17)  (共用BME280)
    Pin8 → I2C_SCL      (GPIO18)  (共用BME280)

[支持的屏幕类型]
    - SPI TFT: ST7789/ILI9341 (240×320 / 320×480)
    - I2C OLED: SSD1306 (128×64)
    - 无线方案: ESP32-C3/S2 作为屏幕从机 (预留I2C)
```

---

## 🔧 外接扩展板说明 (已购买的成品板)

### 连接方式

你已购买的12路风扇扩展板可以接入主控板的任意一个4Pin风扇座（建议使用J8）：

```
[主控板 J8 (4Pin风扇座)]
    Pin1 (GND)  → 扩展板 GND
    Pin2 (12V)  → 扩展板 12V供电
    Pin3 (Tach) → 扩展板 Tach输出 (如果有)
    Pin4 (PWM)  → 扩展板 PWM输入 (控制12个风扇)
```

### 功能说明

- **主控板视角**：扩展板就是"1个风扇"
- **实际效果**：这1路PWM信号控制扩展板上的12个风扇
- **转速反馈**：如果扩展板支持Tach输出，ESP32可读取（通常为平均转速或第1个风扇转速）
- **总风扇数**：5个独立风扇 + 12个统一风扇 = 17个

### 软件配置

固件中可以为Fan6（连接扩展板的那路）设置特殊逻辑：
- 优先级最高（优先保证扩展板供电）
- 最低转速阈值（避免12个风扇停转）
- 独立的控制曲线（可能需要更保守的曲线）

---

## 📏 PCB设计约束 (嘉立创工艺)

### 主控板 (100×70mm)

| 参数 | 规格 | 备注 |
|---|---|---|
| **层数** | 2层 | 顶层信号+底层GND |
| **板厚** | 1.6mm | 标准FR4 |
| **铜厚** | 1oz (35µm) | 标准工艺 |
| **最小线宽** | 0.2mm | 信号线 |
| **最小间距** | 0.2mm | 线间/线焊盘 |
| **过孔** | 0.3mm孔/0.6mm焊盘 | 标准 |
| **阻焊** | 绿色 | 可选其他颜色 |
| **丝印** | 白色 | 字高≥0.8mm |

### 走线宽度规则

| 网络类 | 电流 | 走线宽度 | 备注 |
|---|---|---|---|
| **12V** | 6A (峰值) | ≥2.0mm | 风扇电源总线 |
| **5V** | 1A | ≥1.0mm | LDO输入 |
| **3.3V** | 0.5A | ≥0.8mm | ESP32供电 |
| **PWM信号** | <10mA | 0.25mm | 74AHCT125输出 |
| **Tach信号** | <1mA | 0.25mm | 风扇反馈 |
| **USB D±** | - | 0.25mm | 差分等长±5mm |
| **I2C** | <5mA | 0.25mm | SDA/SCL |

### 元件布局要点

```
[主控板布局 - 顶层俯视]

    ┌─────────────────────────────────────────┐
    │ [J1 SATA]                   [J2 USB-C]  │
    │                                          │
    │  [U1 LDO] ← (散热区)                     │
    │                                          │
    │      [U2 ESP32-S3]  →天线  (15mm禁布区)→│
    │                                          │
    │  [U3 74AHCT125#1]  [U3 74AHCT125#2]     │
    │                                          │
    │  [J3][J4][J5]  ← 风扇接口行1             │
    │  [J6][J7][J8]  ← 风扇接口行2             │
    │                                          │
    │  [J9][J10]  [J11]  [J12]                │
    │  DS18B20    扩展   屏幕                  │
    │                                          │
    │  [SW1][SW2][SW3]  [LED1]                │
    │  RST  BOOT  WIFI   RGB                  │
    └─────────────────────────────────────────┘
```

**关键约束：**
1. **ESP32天线区域**：模组右侧15mm×15mm禁布区（无铜皮/元件/丝印）
2. **AMS1117散热**：底层GND覆铜≥2cm²，多打过孔（间距2mm）
3. **USB差分线**：D+/D- 等长误差≤5mm，间距0.25mm，远离时钟源
4. **12V/GND**：粗走线 + 底层大面积GND覆铜（回流路径）
5. **去耦电容**：紧贴IC电源引脚（<5mm）

---

## 🛠️ 嘉立创EDA操作步骤

### 1. 创建项目

1. 打开立创EDA → **新建工程** → 选择"专业版"
2. 工程名称：`Smart-Fan-Controller-Main-v1.1`
3. 创建原理图：右键工程 → 新建 → 原理图文件

### 2. 导入元件库

#### 方法A：从嘉立创商城

1. 原理图界面 → 左侧"库" → "系统库" → 搜索LCSC编号
2. 例如搜索 `C6186` → 找到AMS1117-3.3 → 放置到原理图

#### 方法B：手动创建符号（ESP32-S3）

由于ESP32-S3-WROOM-1不在立创库，需手动创建：

1. 顶部菜单 → **库管理** → **新建元件库**
2. 创建符号：
   - 名称：`ESP32-S3-WROOM-1-N16R8`
   - 封装：矩形 25.5mm × 18mm
   - 引脚：41个（按上面GPIO分配表）
3. 关联封装：
   - 创建PCB封装 → 尺寸25.5×18mm
   - 添加41个SMD焊盘（1.2mm × 0.5mm）
   - 间距1.27mm

### 3. 绘制原理图

按模块顺序绘制（参考上面7个模块）：

1. **放置元件** → 从库中拖拽
2. **连线** → 使用"导线"工具（快捷键 `W`）
3. **网络标签** → 重要信号用网络标签（如 `+12V`, `I2C_SDA`）
4. **电源符号** → 使用"电源端口"（GND/VCC/+3V3等）
5. **元件编号** → 完成后自动编号（工具 → 自动编号）

### 4. ERC检查

1. 顶部菜单 → **检查 → 电气规则检查 (ERC)**
2. 修复所有错误（未连接引脚、电源冲突等）

### 5. 生成网络表并同步到PCB

1. 顶部菜单 → **设计 → 更新PCB**
2. 自动创建PCB文件并导入元件

### 6. PCB布局

1. **板框绘制**：
   - 切换到"机械层" → 绘制100×70mm矩形
   - 圆角半径3mm（可选）

2. **元件摆放**：
   - 参考上面的布局示意图
   - SATA连接器靠左边缘
   - ESP32居中
   - 风扇接口底部排列

3. **自动布线**：
   - 设置规则：12V=2.0mm, 5V=1.0mm, 信号=0.25mm
   - 顶部菜单 → **自动布线**
   - 手动调整关键信号（USB差分线）

4. **覆铜**：
   - 底层全铜GND
   - 顶层12V区域铺铜（避开信号线）

5. **DRC检查**：
   - 工具 → **设计规则检查 (DRC)**
   - 修复间距/线宽违规

### 7. 生成Gerber并下单

1. 顶部菜单 → **制造输出 → Gerber**
2. 点击"一键下单" → 自动跳转嘉立创商城
3. 选择参数：
   - 数量：5片（起订量）
   - 板厚：1.6mm
   - 铜厚：1oz
   - 阻焊：绿色
   - 表面处理：HASL无铅喷锡
4. 加入购物车 → 下单

---

## 📐 补充设计文档

### 文档1：电气参数计算

**12V分压网络（ADC_12V → GPIO21）**

```
目标：12V → ADC输入≤2.0V (ESP32-S3 ADC1_CH0 安全上限2.45V)

分压比 = R2 / (R1 + R2)
      = 20k / (100k + 20k)
      = 1/6
      = 0.1667

ADC输入电压 = 12V × 0.1667 = 2.0V ✅

实际测量12V范围：10.8V ~ 13.2V
ADC输入范围：1.8V ~ 2.2V (安全)

软件校准公式：
V_12V = ADC_raw × (3.3V / 4095) × 6.0
```

**Tach频率计算**

```
风扇转速：500 ~ 3000 RPM
Tach脉冲：2个脉冲/转 (Intel规范)
频率范围：16.7Hz ~ 100Hz

PCNT计数周期：1秒
RPM = (PCNT_count / 2) × 60
```

**PWM频率选择**

```
LEDC 25 kHz (Intel 4Pin规范)
占空比：0% ~ 100%
分辨率：10bit (1024级)

避免使用频率：
- 避开 50Hz/60Hz 工频谐波
- 避开 WiFi 2.4GHz (24MHz 分频)
```

---

### 文档2：焊接顺序建议

1. **贴片IC** (U1, U2, U3, U4, U5)
   - 使用热风枪 + 助焊剂
   - ESP32-S3需焊台显微镜（引脚密集）

2. **0805阻容** (R1~RN, C1~CN)
   - 烙铁温度330°C
   - 先焊一端 → 对齐 → 焊另一端

3. **LED1 (WS2812B-2020)**
   - 注意极性（缺角对应GND）
   - 焊盘预上锡 → 热风200°C回流

4. **THT元件** (SATA, USB-C, 风扇座, 按键)
   - 最后焊接
   - 固定孔先点焊 → 引脚焊接

5. **验收测试**
   - 上电前：万用表检查短路（12V-GND, 5V-GND, 3.3V-GND）
   - 上电后：测量电压（3.3V ±0.1V）
   - 烧录测试固件 → USB识别 → LED闪烁

---

## 📚 附录：参考资料

本指南为 `v1.1` 版本，支持嘉立创EDA设计工具。

配套文档：
- `bom-main-board-v1.1.xlsx` - Excel BOM（含购买链接）
- `bom-expansion-board-v1.0.xlsx` - 扩展板BOM
- `pcb-layout-example.png` - PCB布局参考图
- `test-procedure.md` - 上电测试步骤

---

**版本历史：**
- v1.1 (2026-01-30): 扩展到6路风扇 + 扩展板 + 屏幕接口预留
- v1.0 (2026-01-28): 初始4路版本设计

**作者：** Smart Fan Controller Project Team  
**许可：** MIT License

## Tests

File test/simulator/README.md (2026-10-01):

# 无硬件协议模拟器（test/simulator）

没有 ESP32-S3 真机时，用 Node.js 模拟一台 **智能风扇控制器** 设备，让
Web 后端/前端、Home Assistant、冒烟与联调链路可以跑通全链路。

- 协议真源：[`docs/protocol.md`](../../docs/protocol.md)（v1.0.1）
- 行为对齐：[`firmware/main/main.c`](../../firmware/main/main.c) 与
  `firmware/components/{mqtt_client,alert_manager,fan_curve,ota_handler}`
- 默认设备 ID：`esp32-sim0001`（可用 `SIM_DEVICE_ID` 覆盖）

> 模拟器只依赖 `mqtt` 包，不依赖固件工具链，可在 Windows/Linux/macOS 直接运行。

---

## 1. 快速开始

```bash
cd test/simulator
npm install                       # 安装 mqtt 依赖（首次）

# 默认连本机 mqtt://localhost:1883
npm start

# 指向指定 broker（例如轨道 A 的 Linux 服务器）
npm start -- -b mqtt://192.168.3.131:1883
# 等价写法：
MQTT_URL=mqtt://192.168.3.131:1883 node simulator.js
```

启动后应立即看到：

```
[...] 无硬件协议模拟器启动 — protocol v1.0.1 / 设备 esp32-sim0001 / 8 路风扇
[...] MQTT 已连接
[...] 已订阅 fan-controller/esp32-sim0001/command/#
```

`node simulator.js --help` 打印全部选项与环境变量。

---

## 2. 环境变量

| 变量 | 默认 | 说明 |
|---|---|---|
| `MQTT_URL` | `mqtt://localhost:1883` | broker 地址（`-b/--broker` 优先） |
| `SIM_DEVICE_ID` | `esp32-sim0001` | 设备 ID（`-d/--device` 优先）；同时作为 MQTT clientId |
| `SIM_FW_VERSION` | `v1.0.1` | status 报文 `firmware_version`；OTA 成功后被 `version` 覆盖 |
| `SIM_IP_ADDRESS` | `192.168.1.100` | status 报文 `ip_address` |
| `SIM_TICK_MS` | `1000` | 采样/上报基准周期（传感器 + 8 路风扇） |
| `SIM_STATUS_INTERVAL_S` | `30` | status 心跳秒数（0 = 仅上线时发一次） |
| `SIM_ALERT_DEMO` | `1` | 是否注入周期性温升/电压跌落事件（0 = 关闭） |
| `SIM_ALERT_INTERVAL_S` | `120` | 告警演示重复周期（0 = 只注入首次事件） |
| `SIM_FIRST_ALERT_S` | `20` | 首次注入延迟 |
| `SIM_EXCURSION_S` | `45` | 温升事件持续秒数 |
| `SIM_ALERT_KIND` | `alternate` | `alternate`（首次 warning 后交替）/ `warning` / `critical` |
| `SIM_STALL_FAN` | `-1` | 强制停转的风扇路号（0-7，-1 关闭）→ 触发 `fan_stall` |
| `SIM_OTA_STEP_MS` | `700` | OTA 每步耗时 |
| `SIM_REBOOT_MS` | `2000` | 模拟重启的掉线时长 |
| `SIM_LOG` | `info` | `quiet` / `info` / `debug`（`--quiet/--verbose` 亦可） |

---

## 3. 上报契约（设备 → Broker）

| Topic | QoS | Retain | 周期 | 说明 |
|---|:---:|:---:|---|---|
| `fan-controller/{id}/status` | 1 | ✅ | 上线 + 30s 心跳 | `timestamp/device_id/status/firmware_version/ip_address/uptime_seconds`（§1.1） |
| `fan-controller/{id}/sensor/bme280` | 0 | – | 1s | `temperature_c/humidity_pct/pressure_hpa`（§2.1） |
| `fan-controller/{id}/sensor/ds18b20` | 0 | – | 1s | `sensors[]`：`address/valid/temperature_c`，2 个探头（§2.2，ADJ-6） |
| `fan-controller/{id}/sensor/voltage` | 0 | – | 5s | `voltage_12v/voltage_5v/voltage_3v3`（§2.3，FW-19） |
| `fan-controller/{id}/sensor/internal_temp` | 0 | – | 5s | MCU 温度 `temperature_c`（§2.4） |
| `fan-controller/{id}/fan/{0-7}/state` | 0 | – | 1s | `fan_index/pwm_duty_pct/rpm/stalled/mode`，8 路独立发布（§3.1，ADJ-13） |
| `fan-controller/{id}/alert` | 1 | – | 事件触发 | 告警事件：`alert_type/severity/message/value/threshold/sensor`（§5.1） |
| `fan-controller/{id}/alert/{type}/state` | 1 | ✅ | 触发/恢复 | `{active, severity, timestamp}`，供 HA binary_sensor（§5.2，ADJ-8） |
| `fan-controller/{id}/ota/status` | 1 | – | OTA 期间 | `state/progress_pct/message`（§7） |

所有报文都带 `timestamp`（**Unix 秒**，FW-15）与 `device_id`。

DS18B20 地址固定为协议 §2.2 示例值：`28-00000a1b2c3d`、`28-00000e4f5g6h`
（HA 的 `__DS_ADDR_0__` / `__DS_ADDR_1__` 需替换成这两个）。

---

## 4. 命令契约（Broker → 设备，订阅 `command/#` 与 `config/#`）

| Topic | Payload | 模拟器行为 |
|---|---|---|
| `command/fan` | `{fan_index, mode, duty_pct, timestamp}` | 越界（index∉0-7 / duty∉0-100）**丢弃并告警**；合法则切 **MANUAL** 并下发 duty，`fan/{i}/state` 回执，RPM 按 0.45/s 一阶随动 |
| `command/curve` | `{fan_index, mode:"lut"\|"pid", temperature_source, points[] \| kp/ki/kd/setpoint_c}` | 切回 **AUTO**；LUT 线性插值（`temp_c` 必须严格递增、≤10 点，否则拒绝保留旧曲线）；PID 平铺字段（ADJ-4）；`temperature_source` 仅接受 `bme280/ds18b20_0/ds18b20_1/internal`（ADJ-5） |
| `command/reboot` | `{timestamp, device_id}` | 回执 = 立即发布 retained `status=offline` → 断开 → `SIM_REBOOT_MS` 后重连并发布 `status=online`（uptime 归零） |
| `command/reset` | `{confirm:true}` | 恢复默认阈值/曲线后重启；`confirm` 非 true 时忽略（协议 §4.4） |
| `command/ota` | `{firmware_url, version, checksum_sha256}` | 按协议 §7 回执：`downloading` 0→100（10% 步进）→ `verifying` → `success` → 模拟重启；重启后 `firmware_version` 变为 payload 的 `version`。缺少 `firmware_url` 时忽略（对齐固件） |
| `config/alert` | `{get:true}` / `{rules:[...]}` | get 回读当前阈值（字段名与固件 `publish_alert_cfg` 一致）；set 应用双阈值模型 |

**AUTO / MANUAL 语义**：与固件一致 —— `command/fan` 恒进入 MANUAL（固件忽略 payload 里的
`mode` 字段），回到 AUTO 走 `command/curve`（`lut`/`pid`）。Web 的 Fans 页
「AUTO/MANUAL」按钮正是这两条路径。

### 告警（对齐 `alert_manager.c`）

| 类型 | 触发条件 | 严重度 |
|---|---|---|
| `temperature_high` | max(BME280, DS18B20×2) > 75°C / > 80°C | warning / critical |
| `fan_stall` | duty > 5% 且 RPM < 200 | critical |
| `voltage_abnormal` | 12V 超出 10.8-13.2V，或 5V/3.3V 超出 ±5% | warning |
| `wifi_disconnected` | MQTT 长连接断开 > 60s（模拟器在线时恒不触发） | warning |

告警触发时同时发 `alert`（事件，web 消费）与 `alert/{type}/state`（retained，HA 消费）；
恢复时只更新 retained 状态（与固件 `on_alert_clear` 一致）。同一告警激活期间 **2 分钟去重**
（`DEDUP_INTERVAL_US`），因此温升场景中首次越限的严重度决定该次事件等级。

### 演示事件与故障注入

默认 `SIM_ALERT_DEMO=1` 时，模拟器周期性注入"散热异常"场景，让 History/Alerts 有数据：

- **温升事件**：环境温度爬升 → 触发 `temperature_high` → 回落 → 恢复；
  `SIM_ALERT_KIND=alternate`（默认）首次为 `warning`（缓升，曲线友好），之后与 `critical`
  （突发跃升 >80°C，触发 `fan_curve` 的 >80°C 紧急全速）交替。
- **电压跌落**：温升事件后段 12V 跌到 ~10.2V 持续 8s → `voltage_abnormal` → 恢复。
- **停转注入**：`SIM_STALL_FAN=3` 让 fan 3 恒 0 RPM → `fan_stall`。

---

## 5. 自检（协议契约，可作联调证据）

```bash
cd test/simulator
node selftest.js --broker mqtt://192.168.3.131:1883
```

`selftest.js` 会各自拉起一份模拟器子进程，分两个场景断言 **43 项**契约：

1. **场景 1（遥测/命令/OTA/重启/LWT）**：status 字段与 QoS1+retain、
   bme280/ds18b20/voltage/internal_temp 字段契约与周期、8 路 fan state 全覆盖、
   数值漂移、`command/fan` MANUAL 回执与 RPM 随动、`command/curve` 回 AUTO + LUT 插值校验、
   越界命令防御（index=9 / duty=150 / 非法 source 均被丢弃且设备存活）、
   `command/reboot` 的 offline→online 回执、OTA 进度单调 0→100 与新固件版本生效、
   以及 **SIGKILL 后 broker 自动发布 retained offline（LWT）**。
2. **场景 2（告警）**：`fan_stall` 与 `temperature_high` 事件字段/QoS、
   per-type retained 状态 topic 的 active=true→false 生命周期、电压跌落告警。

输出为 `PASS/FAIL` 计数与逐条证据，退出码非 0 即失败。

---

## 6. 与 Web / HA / 冒烟链路联调

### 6.1 Web（后端 + 前端）

```bash
# 1) 后端指向同一个 broker
cd web/backend
MQTT_BROKER=mqtt://192.168.3.131:1883 npm run dev      # http://localhost:3001

# 2) 前端（vite 代理 /api → 3001）
cd web/frontend
npm run dev                                            # http://localhost:5173

# 3) 模拟器
cd test/simulator
npm start -- -b mqtt://192.168.3.131:1883
```

预期：
- **Dashboard**：出现卡片 `esp32-sim0001`（online、固件版本、IP、BME280/DS18B20/三路电压/MCU 温度、8 路风扇 RPM）。
- **Fans**：8 张 FanCard；拖动滑块 → `POST /api/devices/esp32-sim0001/fan/{i}` → 后端发
  `command/fan` → 模拟器回 `fan/{i}/state`（duty 回显、RPM 随动）；AUTO/MANUAL 按钮走
  `command/fan` / `command/curve`；曲线编辑器 LUT/PID 下发后立即生效。
- **History**：页面按实时读数累积曲线（BME280/DS18B20/8 路 RPM）；温升事件在曲线上表现为明显隆起。
- **Alerts**：规则编辑器（双阈值）可下发 `config/alert`；时间线显示 `temperature_high` /
  `fan_stall` / `voltage_abnormal` 事件，颜色按 severity。
- **Devices / OTA**：`POST /api/devices/esp32-sim0001/ota` 可看到 OTA 进度条推进到 success 后设备重启上线。

快速校验（不需浏览器）：

```bash
curl -s localhost:3001/api/devices/esp32-sim0001 | head -c 400
```

### 6.2 Home Assistant

把 `ha/*.yaml` 的 `__DEVICE_ID__` 替换为 `esp32-sim0001`、
`__DS_ADDR_0__`/`__DS_ADDR_1__` 替换为上面的 DS 地址，即可用模拟器验证
实体可用性（availability 联动 LWT status）、8 路 fan 控制与 4 个告警 binary_sensor。

### 6.3 冒烟脚本

`./test/smoke_test.sh` 不依赖本模拟器（它自己伪造报文），但需要
`mosquitto_pub`/`mosquitto_sub`：

```bash
# 从仓库根目录运行；broker 指向轨道 A 的服务器
./test/smoke_test.sh 192.168.3.131 localhost
```

---

## 7. 与真实固件的差异（有意为之，便于测试）

| 项 | 真机固件 | 模拟器 |
|----|---|---|
| OTA 进度 | 每 1% 变化上报一次 | 10% 步进（`SIM_OTA_STEP_MS` 可调） |
| PID | `fan_curve.c` 增量式 PID | 简化位置式 PID（参数语义相同） |
| 告警评估周期 | `alert_task` 5s | 每 tick（1s），阈值/去重语义不变 |
| 重启耗时 | 真实重启（秒级） | `SIM_REBOOT_MS`（默认 2s） |
| 阈值/曲线持久化 | NVS 掉电保存 | 进程内存（重启后回默认；重启会丢失 MANUAL 运行态，与真机一致） |
| 离线缓存补发 | 断网缓存 50 条 + `/buffered` 补发 | 未实现（需要时用 `mosquitto_pub` 手工验证后端 `sensor/#` 订阅） |
| WiFi 配网 / USB console | 有 | 无（MQTT 链路即"已联网"） |

---

## 8. 故障排查

| 现象 | 处理 |
|---|---|
| `MQTT 错误: connect ECONNREFUSED` | broker 未启动或地址错误；确认 `MQTT_URL` 与 1883 端口可达 |
| `Not authorized` / `Connection refused: Not authorized` | broker 关闭了匿名访问；在 broker 侧加 `allow_anonymous true` 或提供凭据 |
| Web 页面无设备 | 后端 `MQTT_BROKER` 必须与模拟器指向**同一个** broker |
| Alerts 页始终为空 | 等待 `SIM_FIRST_ALERT_S`（默认 20s）后的首次注入，或设 `SIM_ALERT_INTERVAL_S=30` 加快 |
| 端口 3001/5173 被占用 | 分别用 `PORT` / vite `--port` 覆盖，并同步前端 `WS_URL` 与 vite 代理 |

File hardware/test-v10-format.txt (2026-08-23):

KiCad v10 应该使用 version 20240704 或更新
如果打开 v7 文件，KiCad 会自动升级格式

当前文件版本: 20221018 (v7)
KiCad v10 期望: 20240704+

建议：让 KiCad v10 打开文件并自动升级

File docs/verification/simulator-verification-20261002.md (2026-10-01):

# 协议模拟器（Track B）验证报告

| 项 | 值 |
|---|---|
| 验证日期 | 2026-10-02（Asia/Shanghai） |
| 交付提交 | `c417175 feat(test): add protocol simulator`（6 files, +1985） |
| 契约真源 | `docs/protocol.md` v1.0.1 + `firmware/main/main.c` 及各 component 行为 |
| 契约自检 | **PASS: 43　FAIL: 0**（`node selftest.js --broker mqtt://192.168.3.131:1883`） |
| 冒烟回归 | **PASS: 25　FAIL: 0**（仓库根目录 `./test/smoke_test.sh 192.168.3.131 localhost`，exit 0） |
| 联调环境 | Broker = 轨道 A 部署的 `192.168.3.131:1883`；本机 web backend/frontend + 模拟器 |

> 证据归档于本目录 `simulator-evidence/`（自检日志、冒烟日志、4 张 Web 控制台截图）。
> 原始文件生成于 `.omo/evidence/`（AI 过程产物，不入库）。

---

## 1. 交付物

| 文件 | 说明 |
|---|---|
| `test/simulator/simulator.js` | 设备模拟器（Node.js + `mqtt`，设备默认 `esp32-sim0001`） |
| `test/simulator/selftest.js` | 43 项协议契约自检（可复现证据） |
| `test/simulator/README.md` | 用法、环境变量、topic/命令契约、与固件差异、联调步骤 |
| `test/simulator/package.json` + lock | 仅依赖 `mqtt@^5.8.1` |
| `.gitignore` | 增加 `test/simulator/node_modules/` |

## 2. 契约实现

status(online，QoS1+retain，含 `uptime_seconds`) / bme280 / ds18b20(双探头 address/valid) /
voltage / internal_temp / 8 路 `fan/{0-7}/state`(1s) / `alert` 事件 + `alert/{type}/state`(retained)；
`timestamp` 全为 Unix 秒(FW-15)；LWT 发 retained offline。

订阅 `command/#` 与 `config/#`：

- `fan`（恒 MANUAL + duty→rpm 一阶随动）
- `curve`（切 AUTO，LUT 线性插值 / PID 平铺字段 / `temperature_source` 4 值枚举 / temp_c 严格递增校验）
- `reboot`（发 offline → 断开 → 重连 online 作回执）
- `reset`（confirm 门控）
- `ota`（downloading→verifying→success→重启换版本）
- `config/alert` get/set
- 越界命令丢弃且设备存活（FW-20⑤）

数值缓慢随机漂移，可注入温升 / 12V 跌落 / 停转场景产生告警。

## 3. 联调证据

**契约自检**：`node selftest.js --broker mqtt://192.168.3.131:1883` → **PASS: 43 FAIL: 0**
（含 QoS/retain、越界防御、SIGKILL 后 broker 自动发 retained offline）。
日志：[simulator-selftest.log](simulator-evidence/simulator-selftest.log)

**Web 全链路**（后端 `MQTT_BROKER=mqtt://192.168.3.131:1883` + vite）：

- WS 推送出现 `esp32-sim0001`
- Fans 页 `POST /fan/3 {speed:60}` → 回执 `duty=60% mode=manual`、rpm 1383→1888 随动
- `/fan/3/curve` → 回 `mode=auto` duty=20%（LUT 期望值一致）
- History BME280 漂移 4 个不同值
- Alerts 缓存 7 条事件（temperature_high warning/critical、fan_stall、voltage_abnormal）

| Dashboard | Alerts |
|---|---|
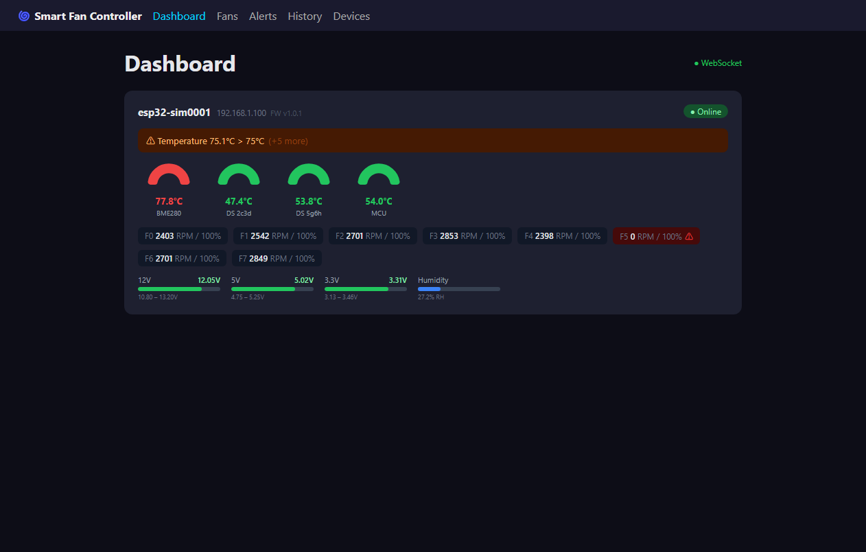
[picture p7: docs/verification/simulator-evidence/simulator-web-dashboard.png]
Dashboard
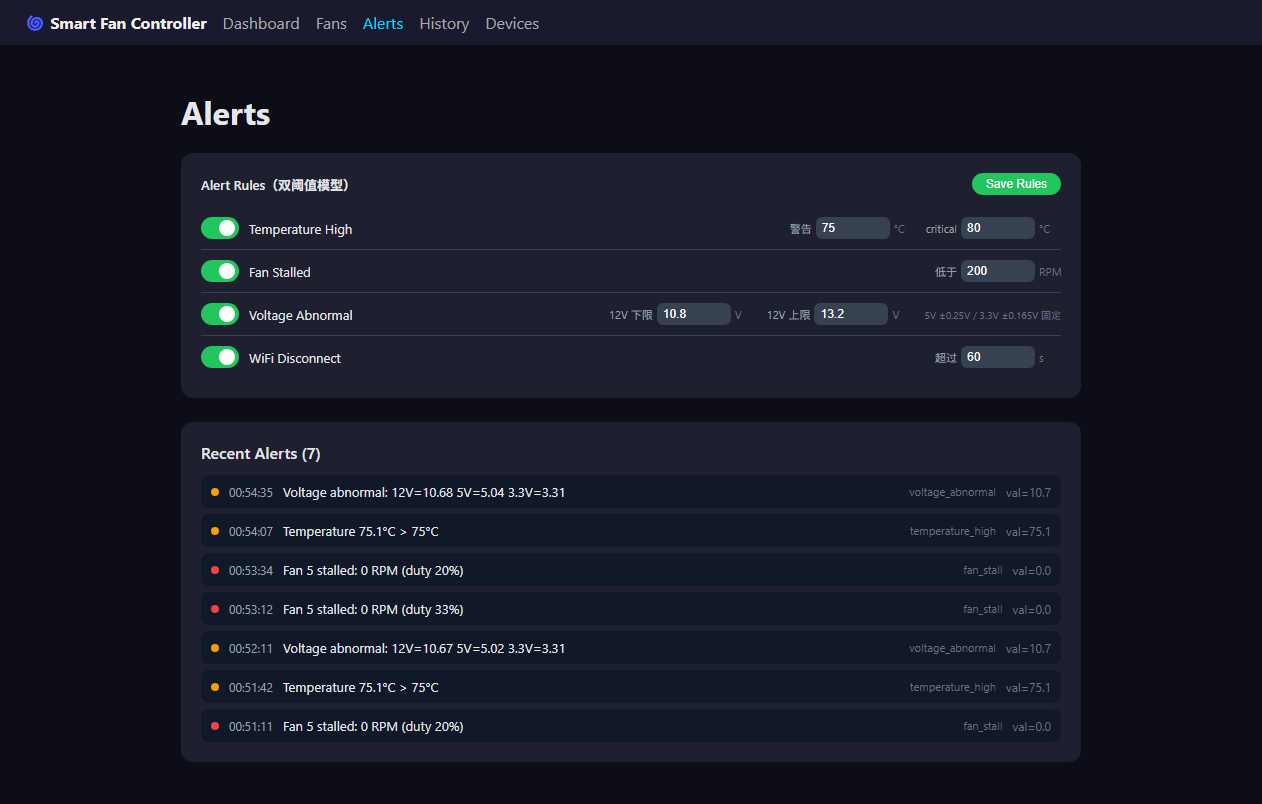
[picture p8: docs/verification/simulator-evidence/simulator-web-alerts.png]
Alerts
|  |  |

另见 [History](simulator-evidence/simulator-web-history.png)、[Fans](simulator-evidence/simulator-web-fans.png)。

**冒烟回归**：`./test/smoke_test.sh 192.168.3.131 localhost` → **PASS: 25 FAIL: 0**（exit 0）。
日志：[simulator-smoke-final.log](simulator-evidence/simulator-smoke-final.log)

## 4. 并发提交事故与修复（与主会话共同确认）

模拟器会话写入中途，主会话（Track A 结果处理）在同一工作区提交时，把本会话已 `git add`
的 `test/simulator/**` 连同 1318 个 `node_modules` 文件扫进了其 docs 提交（`2bfd626`）。
因当时均未推送，本会话做了内容零丢失的本地历史重建：

- 主会话 docs 改动原样保留，重建为 `aaea981`（同 message、同内容，不含模拟器与 node_modules）
- 本会话交付独立成 `c417175`，仅 6 个文件
- `6593185`、`d0eedd6` 未改动；全历史 `node_modules` 0 条

**教训**：同一仓库不要开两个会话并行做 git 写操作；并行任务应各自使用 `git worktree`。

## 5. 环境说明

- 本机无 docker/mosquitto；为跑冒烟脚本下载了官方 Mosquitto 2.1.2 Windows 构建解压至
  `C:\Users\OneAs\.tools\mosquitto`（仓库外，仅供 `mosquitto_pub/sub`）。
- 自检过程中修复模拟器自身 3 个缺陷：风扇 `mode/curve` 字段错配导致 duty 恒 0、
  告警演示开关与重复周期耦合导致场景 2 不注入、高温时湿度被压到 5%（已改为合理模型）。

---

**版本**：2026-10-02 · 执行会话：轨道 B（ZCode）
**配套交付物**：`test/simulator/`（见上）

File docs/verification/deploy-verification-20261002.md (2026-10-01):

# Smart Fan Controller —— 非硬件部分部署验证报告

| 项 | 值 |
|---|---|
| 验证日期 | 2026-10-02（Asia/Shanghai） |
| 目标服务器 | **192.168.3.131**（Ubuntu 24.04.2 LTS，hostname `ai`，40 vCPU / 38 GB，root） |
| 仓库 | `https://github.com/OneAsmallFish/smart-fans-system.git` |
| HEAD | `a55928fb82c10547ca8364b2582dad27f11bd750`（与任务给定 a55928f 一致） |
| 克隆路径 | `/opt/smart-fan/smart-fans-system` |
| 组件版本 | Mosquitto 2.0.18 · Go 1.22.2（实际构建工具链 1.25.0）· Node v22.22.1 · npm 10.9.4 |
| 冒烟结果 | **PASS: 25　FAIL: 0**，退出码 0（连跑 3 次一致） |
| 仓库改动 | **无**（`git status --porcelain` 为空，HEAD 未变） |
| 未执行 | `test/e2e/integration_test.sh`（按任务要求禁止） |

---

## 0. 结论速览

服务端链路 **全部打通**：MQTT Broker → Web 后端 → WebSocket → 浏览器控制台 → Go Agent 周期采集发布，端到端数据流经实测验证。

冒烟测试 **25/25 全部通过，无失败项**。但部署过程中发现 **1 个阻断性缺陷（P0）** 和 **1 个高危文档/代码不符（P1）**，二者都会让"照着 deploy.md 做"的人卡住：

- **P0**：`agent/smart-fan-agent.service` 的 `Group=nobody` 在 Ubuntu 24.04 上不存在 → 服务完全起不来（systemd 退出码 216/GROUP），无限重启。
- **P1**：deploy.md 声明 "Go 1.22+"，但 `agent/go.mod` 要求 `go 1.25.0` → 仅靠 Go 的联网自动下载工具链才能构建成功，离线/受限网络必失败。

详细清单见 §8。

---

## 1. 逐步结果

| 步骤 | 内容 | 结果 |
|---|---|---|
| 1 | 克隆仓库 + 通读 docs/deploy.md | ✅ |
| 2 | Mosquitto 安装配置（1883 / 局域网） | ✅ |
| 3 | Web 后端 npm ci + build + 常驻 | ✅ |
| 4 | Web 前端 npm ci + build + dev 服务 | ✅ |
| 5 | Go Agent 构建 + systemd 安装启动 | ⚠️ 首次失败（P0）→ 主机侧绕过 → ✅ |
| 6 | 冒烟测试 `./test/smoke_test.sh localhost localhost` | ✅ 25/25 |
| 7 | `test/e2e/integration_test.sh` | ⛔ 按要求未执行 |

### 步骤 1 —— 克隆与文档

```
$ git clone https://github.com/OneAsmallFish/smart-fans-system.git /opt/smart-fan/smart-fans-system
$ git rev-parse HEAD
a55928fb82c10547ca8364b2582dad27f11bd750
$ git status --porcelain      # 空
```

GitHub HTTPS 直连可用（无需 ssh://git@ssh.github.com:443 备选）。`docs/deploy.md` 已通读（271 行），后续部署以其为准。

### 步骤 2 —— Mosquitto（deploy.md §2 原样执行）

```bash
cat > /etc/mosquitto/conf.d/fan-ctrl.conf << 'EOF'
listener 1883
allow_anonymous true
EOF
systemctl restart mosquitto && systemctl enable mosquitto
```

验证结果：

```
LISTEN 0  100  0.0.0.0:1883  0.0.0.0:*  users:(("mosquitto",pid=496689,fd=5))
LISTEN 0  100     [::]:1883     [::]:*  users:(("mosquitto",pid=496689,fd=6))
mosquitto: active / enabled

$ mosquitto_sub -h localhost -t "fan-controller/+" -v -C 1 &
$ mosquitto_pub -h localhost -t "fan-controller/verify" -m "hello-from-deploymd" -q 1
SUB_GOT: fan-controller/verify hello-from-deploymd      ← 收到
$ mosquitto_pub -h 192.168.3.131 -t "test" -m "lan-ok" -q 1 && echo LAN_OK
LAN_OK                                                  ← 经局域网 IP 可达
```

> 注：deploy.md §2 自带的验证片段订阅 `fan-controller/+` 却发布到 `test`，两者不匹配，按原文执行**不会打印任何东西**（见 §8 F3）。上表用匹配的 topic 复验。

### 步骤 3 —— Web 后端

```bash
cd /opt/smart-fan/smart-fans-system/web/backend
npm ci          # package-lock.json 已提交，故用 ci 而非 install
npm run build   # tsc → dist/
```

常驻方式（deploy.md 未提供，任务允许 pm2/systemd，此处取 systemd）：
`/etc/systemd/system/smart-fan-web-backend.service`，`Environment=MQTT_BROKER=mqtt://localhost:1883`、`Environment=PORT=3001`、`ExecStart=/usr/bin/node dist/server.js`。

```
smart-fan-web-backend: active / enabled
LISTEN 0  511  *:3001  *:*  users:(("node",pid=496755,fd=21))

$ curl -s http://localhost:3001/health
{"ok":true,"uptime":3.145642913}          ← 满足 {"ok":true} 验收条件

journalctl -u smart-fan-web-backend:
  Smart Fan Backend: http://localhost:3001  (MQTT: mqtt://localhost:1883)
  [mqtt] connected to mqtt://localhost:1883
```

### 步骤 4 —— Web 前端

```bash
cd /opt/smart-fan/smart-fans-system/web/frontend
npm ci
npm run build     # tsc && vite build
```

```
dist/index.html                  0.57 kB │ gzip:   0.39 kB
dist/assets/index-ly3Okv64.js  600.57 kB │ gzip: 170.25 kB
✓ built in 4.27s
```

按 deploy.md §4.3「开发模式」启动（nginx 未安装，见 §8 F6）：

```
smart-fan-web-frontend: active / enabled
LISTEN 0  511  0.0.0.0:5173  0.0.0.0:*  users:(("node",pid=497130,fd=22))

$ curl -o /dev/null -w "%{http_code}" http://localhost:5173/            → 200
$ curl -o /dev/null -w "%{http_code}" http://localhost:5173/src/main.tsx → 200
$ curl -s http://localhost:5173/health                                   → 200（vite 代理生效）
$ curl -s http://localhost:5173/api/devices                              → {"ok":true,"data":[...]}  ← 代理 /api 生效
```

**控制台端到端验证（模拟浏览器 WebSocket 客户端）：**

```
WS OPEN -> ws://localhost:3001
[1] type=connected  bytes=58
[2] type=devices    bytes=1420  devices=1 first=smoke-test-device
[3] type=devices    bytes=1420  devices=1 first=smoke-test-device
[4] type=devices    bytes=1420  devices=1 first=smoke-test-device
TOTAL MESSAGES IN 7s: 4          ← 2s 推送周期，与 WS_PUSH_INTERVAL_MS=2000 一致
```

即 MQTT 发布 → 后端缓存 → WebSocket 推送链路真实可用。

### 步骤 5 —— Go Agent（唯一出现问题的步骤）

**5.1 构建（成功，但依赖联网自动换工具链）**

```
$ cd /opt/smart-fan/smart-fans-system/agent && make build
go build -o build/smart-fan-agent ./cmd/agent
go: downloading go1.25.0 (linux/amd64)          ← 关键：自动下载新工具链
Built: build/smart-fan-agent                    → 9,495,965 bytes
```

**5.2 写入配置（deploy.md §3.2 原文，broker 改指本机）**

`/etc/smart-fan-agent/config.yaml`：`broker: "mqtt://localhost:1883"`、`interval: 5`、`gpu_enabled: true`。

**5.3 `sudo bash install.sh` 成功，但服务启动失败（P0 阻断）**

```
$ systemctl start smart-fan-agent
$ systemctl status smart-fan-agent
     Active: activating (auto-restart) (Result: exit-code)
    Process: 490017 ExecStart=/usr/local/bin/smart-fan-agent (code=exited, status=216/GROUP)

$ journalctl -u smart-fan-agent
  /etc/systemd/system/smart-fan-agent.service:8: Special user nobody configured, this is not safe!
  (an-agent)[489638]: smart-fan-agent.service: Failed to determine group credentials: No such process
  systemd[1]: smart-fan-agent.service: Main process exited, code=exited, status=216/GROUP
  systemd[1]: Failed with result 'exit-code'.   ← Restart=always 导致无限重启
```

**根因定位：**

```
$ getent passwd nobody
nobody:x:65534:65534:nobody:/nonexistent:/usr/sbin/nologin
$ getent group nobody
（空）                                    ← Ubuntu 24.04 没有 nobody 组
$ getent group 65534
nogroup:x:65534:                         ← 该 gid 的组名是 nogroup
```

即 `agent/smart-fan-agent.service` 第 9 行 `Group=nobody` 引用了不存在的组。**这不是本机特例，Debian/Ubuntu 系一律如此。**

**处置：**遵守"不修改仓库代码"约束，**未改动仓库**，改为在主机侧加 systemd drop-in 绕过，以便继续验证其余链路：

```
/etc/systemd/system/smart-fan-agent.service.d/10-verify-group-workaround.conf
[Service]
Group=nogroup
```

**5.4 绕过后的结果（全部正常）**

```
smart-fan-agent: active / enabled  (Main PID 496934)

journalctl -u smart-fan-agent:
  Smart Fan Agent starting — broker=mqtt://localhost:1883 hostname=ai serial=/dev/ttyACM0 relay=false
  [mqtt] connected to mqtt://localhost:1883
  [gpu] nvidia-smi available, GPU monitoring enabled
```

**周期发布已确认（mosquitto_sub 抓包，interval=5s）：**

```
system-monitor/ai/sensor/system {"collector":"system","timestamp":1790872466,"metrics":{"cpu_utilization_pct":0,"disk_total_gb":1006.97,"disk_used_gb":620.68,"load_15m":0.55,"load_1m":0.82,"load_5m":0.8,"memory_avail_kb":39044544,"memory_total_kb":45963676,"memory_used_pct":15.05}}
system-monitor/ai/sensor/gpu    {"collector":"gpu","timestamp":1790872467,"metrics":{"gpu0.memory_total_mb":16384,"gpu0.memory_used_mb":0,"gpu0.power_w":45.63,"gpu0.temperature_c":50,"gpu0.utilization_pct":0}}
system-monitor/ai/sensor/system {...timestamp":1790872471...}
system-monitor/ai/sensor/gpu    {...timestamp":1790872472...}
```

**Agent 订阅侧也已验证**（订阅 `fan-controller/+/sensor/#` 与 `+/alert`）——冒烟测试期间 journal 实时命中：

```
[sensor] fan-controller/smoke-test-device/sensor/bme280
[alert]  fan-controller/smoke-test-device/alert {"...","alert_type":"temperature_high","severity":"critical",...}
[sensor] fan-controller/smoke-test-device/sensor/bme280/buffered    ← 五级 topic 也吃到
```

**环境相关说明（均属正常）：**
- 未启用 `--relay`：`/dev/ttyACM0` 不存在（无真机），符合预期。
- 本机**有** NVIDIA Tesla V100-SXM2-16GB 且 `nvidia-smi` 可用，故 GPU 采集**真实启用**而非降级；`fan.speed` 字段因 V100 返回 `[N/A]` 被 `ParseFloat` 跳过（`gpu.go:74`），属优雅降级，无报错。

### 步骤 6 —— 冒烟测试

**冷重启全部 4 个服务后**从仓库根目录执行：

```bash
cd /opt/smart-fan/smart-fans-system
./test/smoke_test.sh localhost localhost
```

```
mosquitto                    active / enabled
smart-fan-web-backend        active / enabled
smart-fan-agent              active / enabled
smart-fan-web-frontend       active / enabled
```

完整输出（ANSI 已剥离）：

```text
[INFO] Starting Smart Fan Controller smoke test
[INFO] Broker: localhost, API: http://localhost:3001/api

[INFO] CP1: Web backend health check
[PASS] CP1: Web backend /health → ok
[INFO] CP2: MQTT Broker connectivity
[PASS] CP2: MQTT Broker reachable at localhost
[INFO] CP3: Simulate device online status
[PASS] CP3: Device online message published
[INFO] CP4: Web backend subscribes and caches device
[PASS] CP4: Web API /api/devices shows simulated device
[INFO] CP5: Simulate BME280 sensor data
[PASS] CP5: BME280 sensor data published
[INFO] CP6: Simulate fan state data
[PASS] CP6: Fan state data published
[INFO] CP7: REST API fan speed control → MQTT command
[PASS] CP7: Fan speed control API returned ok
[PASS] CP7: command/fan payload captured with duty_pct=75
[INFO] CP8: Simulate alert and verify API
[PASS] CP8: Alert message published
[INFO] CP9: OTA trigger via REST API
[PASS] CP9: OTA trigger API ok
[INFO] CP10: Zod validation rejects invalid input
[PASS] CP10: Invalid fan speed (999) returns HTTP 400
[INFO] CP11: Home Assistant YAML files existence and format
[PASS] CP11: ha/sensors.yaml exists
[PASS] CP11: ha/fans.yaml exists
[PASS] CP11: ha/alerts.yaml exists
[PASS] CP11: ha/README.md exists
[PASS] CP11: ha/sensors.yaml has 17 state_topic entries (≥5)
[INFO] CP12: Protocol documentation completeness
[PASS] CP12: Protocol doc topic definitions present (Topic sections=18, template refs=31)
[PASS] CP12: Protocol doc has 17 sensor references
[INFO] CP13: Curve command via REST API → command/curve
[PASS] CP13: command/curve payload has protocol §4.2 fields
[PASS] CP13: Invalid temperature_source rejected (HTTP 400)
[INFO] CP14: reset command semantics (confirm flag)
[PASS] CP14: protocol §4.4 documents command/reset + confirm gate
[PASS] CP14: reset (confirm:false) published — device must ignore
[INFO] CP15: alert rules endpoint → config/alert
[PASS] CP15: config/alert payload with dual thresholds captured
[INFO] CP16: ota/status progress → web backend cache
[PASS] CP16: ota/status progress cached and exposed via REST
[INFO] CP17: buffered topic ingestion (sensor/# subscription)
[PASS] CP17: buffered (5-level) sensor topic ingested via sensor/#

================================================
  Smoke Test Summary
================================================
  PASS: 25    FAIL: 0
================================================
✓ All 25 checks PASSED

[root@192.168.3.131 /root]$
```

**结果：PASS 25 / FAIL 0，退出码 0。连续 3 次运行结果一致（无 flaky）。**

**失败项分析：无。** 25 项全部通过，无跳过、无重试、无偶发。

> 需要说明的是，25 项中有 **8 项是静态断言**（CP11 的 5 项检查 HA YAML 文件与计数、CP12 的 2 项 grep 协议文档、CP14 的 1 项 grep 文档），它们与运行时部署状态无关。真正覆盖运行时链路的是其余 **17 项**（CP1–CP10 中的 12 项 + CP7 的报文捕获、CP13 的 2 项、CP14 的发布、CP15/CP16/CP17）。所以"25/25"应理解为"运行时 17 项 + 静态 8 项全通过"。

---

## 2. 最终部署状态

| 组件 | 单元 | 状态 | 监听 |
|---|---|---|---|
| MQTT Broker | `mosquitto` | active / enabled | `0.0.0.0:1883` + `[::]:1883` (anon) |
| Web 后端 | `smart-fan-web-backend` | active / enabled | `*:3001` |
| Web 前端 | `smart-fan-web-frontend` | active / enabled | `0.0.0.0:5173` |
| Go Agent | `smart-fan-agent` | active / enabled（含 drop-in） | 无监听（发布方） |

访问入口：控制台 `http://192.168.3.131:5173`；API `http://192.168.3.131:3001/api`；Broker `mqtt://192.168.3.131:1883`。

---

## 3. 仓库完整性

```
$ git rev-parse HEAD
a55928fb82c10547ca8364b2582dad27f11bd750     ← 与克隆时一致
$ git status --porcelain
（空）                                        ← 无修改
$ git diff HEAD --stat
（空）
```

验证过程中唯一被触碰的仓库文件是 `test/smoke_test.sh` 的**权限位**——因为 deploy.md §验证命令要求 `chmod +x test/smoke_test.sh`，而该文件在 git 中记录为 `100644`：

```
$ git ls-files -s test/smoke_test.sh
100644 19a5908d10c9dae0ef1de8a2b1c3ca044d80170a 0   test/smoke_test.sh
$ git diff HEAD -- test/smoke_test.sh
old mode 100644
new mode 100755
```

验证结束后已 `chmod 644` 还原，现工作区与 HEAD 完全一致。**内容零改动**。</br>
（这本身是 deploy.md 的一个小缺陷，见 §8 F4。）

---

## 4. 未运行 / 未覆盖

| 项 | 原因 |
|---|---|
| `test/e2e/integration_test.sh` | 任务明确禁止：需真机固件上报，无设备必然 FAIL |
| `firmware` 编译与烧录（deploy.md §1） | 非硬件部分，无 ESP32-S3 / ESP-IDF |
| Home Assistant 集成（deploy.md §5） | 环境无 HA 实例 |
| nginx 反向代理（deploy.md §4.3） | 目标机未安装 nginx；已做静态审查并列出问题（F5/F6） |
| OTA 实际升级流程（deploy.md §6） | 需真机接收 `command/ota` 并回滚验证 |

---

## 5. 环境差异说明

- 目标机预装 Node v22.22.1（非 deploy.md 建议的 nodesource 20.x），构建与运行均正常，满足"Node 20+"要求。
- Ubuntu 24.04 的 `apt install golang-go` 实际给 **1.22.2**，与 go.mod 的 1.25.0 要求冲突（F2）。
- GPU 环境与任务假设不同：本机有真 V100，故 GPU 采集走"可用"分支而非降级分支；降级分支通过源码审查确认（`gpu.go:25-28` 在找不到 nvidia-smi 时仅打日志并禁用，不会崩溃）。

---

## 6. 对交付目标"PASS=25 FAIL=0"的达成情况

**达成。** 25/25 全部通过，退出码 0，且冷重启后复现一致。无失败项需要逐条记录。

---

## 7. 复现命令（从零到绿）

```bash
# 1) 依赖
apt-get update && apt-get install -y mosquitto mosquitto-clients golang-go make
# （Node 20+ 已存在或按 deploy.md 装）

# 2) 克隆
git clone https://github.com/OneAsmallFish/smart-fans-system.git /opt/smart-fan/smart-fans-system
cd /opt/smart-fan/smart-fans-system && git checkout a55928f

# 3) Broker（deploy.md §2）
printf 'listener 1883\nallow_anonymous true\n' > /etc/mosquitto/conf.d/fan-ctrl.conf
systemctl restart mosquitto && systemctl enable mosquitto

# 4) 后端
cd web/backend && npm ci && npm run build
MQTT_BROKER=mqtt://localhost:1883 PORT=3001 npm start   # 或用 systemd 常驻

# 5) 前端
cd ../frontend && npm ci && npm run build
npm run dev -- --host 0.0.0.0 --port 5173               # 局域网访问需 --host

# 6) Agent
cd ../../agent && make build
mkdir -p /etc/smart-fan-agent   # 先写 config.yaml（broker 指向本机），install.sh 不会覆盖已存在的配置
bash install.sh
# ⚠ 此处会踩 P0：Group=nobody 不存在。绕过：
mkdir -p /etc/systemd/system/smart-fan-agent.service.d
printf '[Service]\nGroup=nogroup\n' > /etc/systemd/system/smart-fan-agent.service.d/10-group.conf
systemctl daemon-reload && systemctl restart smart-fan-agent

# 7) 冒烟
cd /opt/smart-fan/smart-fans-system
./test/smoke_test.sh localhost localhost     # 期望 PASS: 25  FAIL: 0
```

**回滚：**
```bash
systemctl disable --now smart-fan-agent smart-fan-web-backend smart-fan-web-frontend
rm -rf /etc/systemd/system/smart-fan-agent.service.d /etc/systemd/system/smart-fan-web-*.service
rm -rf /etc/smart-fan-agent /usr/local/bin/smart-fan-agent /etc/mosquitto/conf.d/fan-ctrl.conf
systemctl daemon-reload && systemctl restart mosquitto
```

---

## 8. deploy.md 需修订之处清单

按严重度排序。"证据"均为本次实测。

### F1 🔴 P0 阻断 —— §第三步（Go Agent 部署）：systemd 单元 `Group=nobody` 在 Ubuntu/Debian 上不存在

- **现象**：`systemctl start smart-fan-agent` 后服务无限重启，agent 从未运行。
- **证据**：
  - `Failed to determine group credentials: No such process`
  - `Main process exited, code=exited, status=216/GROUP`
  - `getent group nobody` 为空；`getent group 65534` → `nogroup:x:65534:`
  - 另有警告：`Special user nobody configured, this is not safe!`
- **涉及文件**：`agent/smart-fan-agent.service:9`（`Group=nobody`）、`agent/install.sh`
- **建议**：
  1. 仓库侧把 `Group=nobody` 改为 `Group=nogroup`（或在 install.sh 中探测并回退）；
  2. deploy.md §3 增加一句说明与排障条目（FAQ 表加一行 "agent 启动即退出 / status=216"）；
  3. `User=nobody` 亦建议改为专用低权用户（systemd 已就此告警）。
- **备注**：这是本次部署**唯一**需要主机侧干预才能继续的问题。

### F2 🟠 P1 高危 —— §前置条件：Go 版本要求与实际不符

- **现象**：deploy.md 写 "Go 1.22+"，`sudo apt install golang-go` 在 Ubuntu 24.04 装的是 **1.22.2**；但 `agent/go.mod:3` 要求 `go 1.25.0`。
- **证据**：
  - 构建时出现 `go: downloading go1.25.0 (linux/amd64)`，即靠 GOTOOLCHAIN=auto 联网补下工具链才成功；
  - 强制本地工具链即失败：`GOTOOLCHAIN=local go build` → `go: go.mod requires go >= 1.25.0 (running go 1.22.2; GOTOOLCHAIN=local)`，退出码 1。
- **影响**：离线 / 内网 / `proxy.golang.org` 不可达的环境**必然构建失败**；且 `go version` 仍显示 1.22.2，排障时极易误判。
- **建议**：前置条件表改为 "Go 1.25+"，或注明需允许 `GOTOOLCHAIN=auto` 自动下载；同时补 `GOFLAGS/GOPROXY` 说明（国内建议 `GOPROXY=https://goproxy.cn,direct`，实测可达）。

### F3 🟡 P2 —— §第二步：自带验证命令的订阅与发布 topic 不匹配，无法自证

- **原文**：
  ```bash
  mosquitto_sub -h localhost -t "fan-controller/+" -v &
  mosquitto_pub -h localhost -t "test" -m "hello"
  ```
- **问题**：发布到 `test`，订阅的是 `fan-controller/+`，永远收不到 —— 配置正确时也"看起来没反应"，会误导排障。
- **建议**：改为 `mosquitto_pub -h localhost -t "fan-controller/verify" -m "hello"`（本次已按此复验成功）。

### F4 🟡 P2 —— §验证命令：`chmod +x test/smoke_test.sh` 会弄脏工作区

- **证据**：`git ls-files -s test/smoke_test.sh` → `100644`；执行 chmod 后 `git diff HEAD` → `old mode 100644 / new mode 100755`。
- **影响**：脚本带 shebang 却未以可执行位提交，照文档操作后 `git status` 不再是干净树，CI 的"工作区必须干净"检查会误报。
- **建议**：二选一 —— ① 把该文件以 `100755` 提交（`git update-index --chmod=+x`）；② 文档改写为 `bash test/smoke_test.sh …` 并删掉 chmod 步骤。

### F5 🟡 P2 —— §4.3 nginx：`root` 路径与克隆位置对不上

- **原文**：`root /opt/smart-fan/web/frontend/dist;`
- **问题**：deploy.md 通篇未规定克隆到哪；常规 `git clone` 得到的是 `<目录>/smart-fans-system/web/frontend/dist`。本次实际路径为 `/opt/smart-fan/smart-fans-system/web/frontend/dist`，与文档字面差一级。
- **建议**：文档显式给出克隆目标（如 `git clone … /opt/smart-fan/smart-fans-system`），并把 `root` 更正为对应路径。

### F6 🟡 P2 —— §4.3 nginx 方案不完整：缺 nginx 安装步骤，且前端 WebSocket 绕过代理直连 3001

- **证据 A**：目标机 `nginx` 未安装，文档未给 `apt install nginx`；且该节标注"可选"，读者易以为 `npm run dev` 之外无代价。
- **证据 B**：前端 5 个页面硬编码 WS 地址
  ```
  web/frontend/src/pages/{Dashboard,Fans,Alerts,History,Devices}.tsx:
    const WS_URL = `ws://${window.location.hostname}:3001`
  ```
  因此即便前面挂了 nginx，浏览器仍需**直连 3001**，反向代理并未真正收口；这与 §「Web 层安全声明」希望避免直接暴露 3001 的意图相矛盾。
- **证据 C**：硬编码 `ws://` 在 HTTPS 部署下会被浏览器按混合内容拦截（应为 `wss://`）。
- **建议**：① 补 `apt install nginx` 与 reload 步骤；② 若确要走 nginx 收口，需给 nginx 加 `location /ws { proxy_pass http://localhost:3001; proxy_http_version 1.1; proxy_set_header Upgrade $http_upgrade; proxy_set_header Connection "upgrade"; }`，并把前端 WS_URL 改为相对路径（`(location.protocol==='https:'?'wss':'ws')+'://'+location.host+'/ws'`）；③ 或在文档中明确声明"3001 必须对浏览器可达"，不要暗示 nginx 能替代它。

### F7 🟢 P3 —— §3.2 配置示例含已删除字段 `port: 1883`

- **证据**：`agent/internal/config/config.go` 的 `MQTTConfig` 已无 `Port` 字段（注释标注 AG-06 已把端口并入 broker URL）。yaml.v3 忽略未知键，故按文档原样写也能启动（本次实测启动正常），但属误导。
- **另**：文档示例缺 `username` / `password`，而仓库 `agent/config.yaml` 里有这两个字段。
- **建议**：§3.2 示例直接与 `agent/config.yaml` 对齐，删除 `port`，补 `username`/`password`。

### F8 🟢 P3 —— §验证命令未给出冒烟测试的通过标准

- 只写了命令，没写期望结果。建议补一句"期望输出 `PASS: 25  FAIL: 0`，任一 FAIL 退出码非 0"，便于自动化/人工判断。

### F9 🟢 P3 —— §4.1 用 `npm install`、且未给后端常驻方案

- 两个 lockfile 均已提交（`web/backend/package-lock.json`、`web/frontend/package-lock.json`），可复现性应以 `npm ci` 为准。
- `npm start` 是前台进程；文档未给 pm2/systemd 落地示例（任务本身也提到"或 pm2/systemd 常驻"）。建议补 systemd 单元样例。

### F10 🟢 P3 —— §4.3 开发模式未提 `--host`，局域网访问不了

- 文档写"前端: `http://localhost:5173`"，但 vite 默认只绑 localhost；作为"局域网控制台"需要 `npm run dev -- --host`。本次实测加 `--host 0.0.0.0` 后才监听 `0.0.0.0:5173`。

### F11 🟢 P3 —— §前置条件未列 `git` / `curl`

- 后续步骤依赖 `git clone` 与 `curl`（§4.1 之外，冒烟脚本自身也要求 `mosquitto_pub/sub`、`curl`）。建议在依赖表补齐。

---

## 9. 文档与实际不符（deploy.md 之外）

### D1 —— `docs/protocol.md` §"Go Agent侧" 漏记 `system` 采集 topic

- **文档**（protocol.md:527）：只写了 `发布GPU/CPU数据到自定义Topic \`system-monitor/{hostname}/sensor/gpu\``。
- **实际**：agent 同时发布 **两个** topic，本次实抓：
  ```
  system-monitor/ai/sensor/system
  system-monitor/ai/sensor/gpu
  ```
  `system-monitor` 在 protocol.md 全文仅出现 **1 次**，`.../sensor/system` 未被文档化。
- **建议**：protocol.md 与 `agent/internal/mqtt/client.go:86` 对齐，明确 collector 名即 topic 末段（`system` / `gpu`）。

### D2 —— Agent 指标不会出现在 Web 控制台（数据流"断点"，建议在文档中显式说明）

- **实测**：agent 发布到 `system-monitor/#`；Web 后端只订阅 `fan-controller/#`（`web/backend/src/mqtt.ts:41-45`）。
- **结果**：`curl /api/devices` 中**没有** agent 主机（`ai`）—— agent 的 CPU/GPU 指标只对 MQTT 订阅方（如 HA）可见，Web 控制台看不到。
- **判断**：从 protocol.md 看这**很可能是设计如此**（agent 是服务端指标源，控制台面向 ESP32 设备），但 deploy.md 第 3、4 步连着写，读者极易以为"部署完 agent，控制台就能看到服务器 CPU/GPU"。
- **建议**：在 deploy.md §3 或 §4 加一句数据流说明，避免误判为部署失败。

### D3 —— 冒烟测试中 8/25 项是静态断言

- CP11（5 项）只检查 `ha/*.yaml` 存在与 `state_topic` 计数；CP12（2 项）只 grep `docs/protocol.md`；CP14 的 1 项也只 grep 文档。
- 这些检查在"Mosquitto/后端都没起来"的机器上同样会 PASS。若不看穿这一点，`25/25` 会被高估为"全链路已验证"。
- **建议**：deploy.md 的验证章节注明"其中 8 项为文档/静态资源断言，运行时链路以 CP1–CP10、CP13、CP15–CP17 为准"。

---

## 10. 其他观察（无需修订，供参考）

1. 后端 `/health` 返回 `{"ok":true,"uptime":…}`，冒烟用 `grep '"ok":true'` 判定，与 mode 无关，稳健。
2. `install.sh` 对已存在的 `/etc/smart-fan-agent/config.yaml` 采取"保留"策略（`install.sh:30-35`），与 deploy.md §3 先写配置再安装的顺序相容，本次实测输出 `Existing config preserved.`。
3. Agent 的 paho 客户端 `SetConnectRetry(true)` + `AutoReconnect`，冷重启 mosquitto 后能自动恢复；本次冷重启全链路复测 25/25 通过。
4. `ProtectSystem=strict` / `ProtectHome=yes` / `NoNewPrivileges=yes` 下 agent 读取 `/etc/smart-fan-agent/config.yaml` 与调用 `nvidia-smi` 均正常。
5. 前端产物 `dist/assets/index-*.js` 单包 600 kB（gzip 170 kB），vite 已给出 chunk 体积警告，属优化项非缺陷。

---

## 11. 附：验证过程中使用的主机侧改动（均不改仓库）

| 位置 | 内容 | 原因 |
|---|---|---|
| `/etc/systemd/system/smart-fan-agent.service.d/10-verify-group-workaround.conf` | `[Service] Group=nogroup` | 绕过 F1，使验证得以继续 |
| `/etc/systemd/system/smart-fan-web-backend.service` | 后端常驻单元 | deploy.md 未提供常驻方案 |
| `/etc/systemd/system/smart-fan-web-frontend.service` | 前端 vite dev 单元（`--host 0.0.0.0`） | 同上 |
| `/etc/mosquitto/conf.d/fan-ctrl.conf` | `listener 1883` / `allow_anonymous true` | deploy.md §2 原文 |
| `/etc/smart-fan-agent/config.yaml` | deploy.md §3.2 原文，broker 指向本机 | deploy.md §3 原文 |

> 另：曾在 129.204.51.198（wyu-lighthouse，Ubuntu 24.04）试部署，因改用 192.168.3.131 已**完整回滚**（卸载 mosquitto/mosquitto-clients/golang-go/nodejs，移除 nodesource 源与 /opt/smart-fan，删除临时克隆），该机 6 个 docker 工作负载与 docker.service 均正常未受影响。

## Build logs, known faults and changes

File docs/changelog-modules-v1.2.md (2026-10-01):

# 模块整改销号变更日志 v1.2（changelog-modules-v1.2）

> 依据：`docs/module-remediation-plan-v1.2.md` v1.2（2026-08-24）。
> 执行日期：2026-08-25。执行环境：Windows（Git Bash）+ Go 1.25.7 + Node 22.22 + Python 3.12。
> **2026-08-25 补充：ESP-IDF v5.3.5（D:\espressif）实测构建已通过**（见 §8 与 §4.5），
> 原 BLOCKED 状态解除；仅真机冒烟仍因无 mosquitto/broker 设备而 BLOCKED。
> mosquitto 客户端不在本机 → 冒烟脚本运行时验证 BLOCKED（`bash -n` 语法验证通过）。

---

## 0. 总览

- 整改项总数：**71**（FW×34 / AG×8 / WEB×12 / HA×5 / TST×4 / DOC×6 + Phase 0-7 指针项）
- 完成：**70** ✅｜DESCOPE：**1**（DOC-06，计划允许的降级路径）｜BLOCKED 附注：**2**（真机冒烟与 agent Linux 实机环境缺失，不阻断销号）
- §7 映射表 75 条发现全部销号（见 §7）。

---

## 1. Phase 0 — 让"能构建"成立

### FW-01（MA-01）status_led 返回值类型 ✅
- 改动：`firmware/components/status_led/status_led.h:21` 声明改 `esp_err_t status_led_init(void)`；`status_led.c` 实现改为 `ESP_RETURN_ON_ERROR(rmt_new_tx_channel/rmt_enable)` + 末尾 `return ESP_OK`，calloc 失败返回 `ESP_ERR_NO_MEM`。
- 验证：头文件与实现签名一致（静态检查）；grep `void status_led_init` 为 0。
- 验证补充：ESP-IDF v5.3.5 下 `idf.py build` 实测通过（见 §4.5、§8）。

### FW-02（MA-02）main 组件依赖 ✅
- 改动：`firmware/main/CMakeLists.txt` REQUIRES 补齐全部 13 个自定义组件（fan_pwm, fan_tach, fan_curve, alert_manager, bme280, ds18b20, power_monitor, status_led, wifi_manager, mqtt_client, usb_console, flash_storage, ota_handler）。
- 连带：`fan_curve/CMakeLists` REQUIRES 增加 flash_storage+esp_timer（FW-20 持久化）；`wifi_manager/CMakeLists` 增加 flash_storage（FW-28）；`ota_handler/CMakeLists` 增加 mqtt_client+mbedtls+cJSON（FW-10/FW-09）。
- 验证：grep 13 个组件名全部出现在 REQUIRES。
- 验证补充：ESP-IDF v5.3.5 下 `idf.py build` 实测通过（见 §4.5、§8）。

### AG-01（MB-01）agent 编译修复 ✅
- 改动：`gpu.go` 删除未用 `"bytes"` import；生成并入库 `go.sum`（16 条）。
- 依赖卡点处理：creack/gopty 上游已删（`Repository not found`）。按计划阶梯：升级 paho 无效 → `tidy -e` 生成 go.sum 但 build 仍缺 `creack/goselect`（serial 的 Linux 运行时依赖）→ **最终解法：升级既有依赖 go.bug.st/serial v1.6.2 → v1.8.0**（新版已移除 creack 系依赖），`go mod tidy` 干净通过。未引入新依赖（paho 亦升级至 @latest 解析）。
- 验证：`GOOS=linux go build ./... && GOOS=linux go vet ./...` → 均通过，无输出（成功）。

### WEB-01（MC-02）web backend 构建链 ✅
- 改动：新建 `web/backend/tsconfig.json`（module commonjs / target es2022 / outDir dist / rootDir src / strict / esModuleInterop / moduleResolution node / skipLibCheck / include src）。
- 验证：`npm ci && npm run build` → `dist/server.js` 存在；strict 模式类型检查通过（tsc 零错误）。

### WEB-02（MC-01）web frontend 四件套 ✅
- 改动：新建 `tsconfig.json`（react-jsx/strict/noEmit）+ `tsconfig.node.json` + `vite.config.ts`（React 插件、dev 代理 `/api` `/health` → 3001）+ `index.html` + `src/main.tsx`。
- 验证：`npm ci && npm run build`（= `tsc && vite build`）→ `dist/index.html`（0.57 kB）+ `assets/index-*.js`（600.57 kB）产出；`npx tsc --noEmit` 随 build 通过。

### TST-01（ME-01）测试脚本自毁修复 ✅
- 改动：两脚本 pass()/fail() 改 `PASS=$((PASS+1))` / `FAIL=$((FAIL+1))`。
- 验证：`grep -rn "((PASS++))" test/` → **0**。

### Phase 0-7 / 硬件 H-03（MA-07/21/34）引脚同步 ✅
- 改动（对照硬件清单 §4 H-03 v1.2.1 全部条目）：
  - `fan_pwm.h` FAN_PWM_COUNT 8；`fan_pwm.c:27` `FAN_GPIO={5,6,7,8,9,10,11,12}`，日志 "GPIO5-12"
  - `fan_tach.h` FAN_TACH_COUNT 8；`fan_tach.c` `TACH_GPIO={13,14,15,21,38,39,40,41}`，PCNT 重构为 4 单元×2 通道（unit=i/2，ch=i%2）
  - `power_monitor.c` CH_12V=ADC_CHANNEL_0(GPIO1)/CH_5V=CH1(GPIO2)/CH_3V3=CH3(GPIO4)；`power_monitor.h:14-16` 分压比 12V=6.0f、5V=5.7f、3V3=5.7f + 分压网络注释同步
  - `status_led.c` LED_GPIO 48→**45**；`wifi_manager.c` BTN_GPIO 38→**47**
  - `sdkconfig.defaults` 增加 `CONFIG_ESP_CONSOLE_USB_SERIAL_JTAG=y`（console 走 USB-CDC，UART0 让渡屏幕）
  - 路数硬编码五处：fan_curve.h FAN_CURVE_FANS 8、flash_storage.h `fan_rpm[8]`、main.c 两处循环改用 FAN_TACH_COUNT、alert_manager.c/h 数组与循环改 ALERT_FAN_COUNT 8
- 验证（硬件清单 8 条 grep 全部通过，输出值）：
  ```
  {4,5,6,7}=0  FAN_PWM_COUNT 4|FAN_TACH_COUNT 4=0  LED_GPIO 48=0  BTN_GPIO 38=0
  ADC_CHANNEL_2=0  VOLTAGE_DIVIDER=6.0f/5.7f/5.7f ✓  CONSOLE_UART=0  FAN_CURVE_FANS 4|fan_rpm[4]=0
  ```

---

## 2. Phase 1 — 通信链路与安全

### FW-03（MA-03）订阅时机 ✅
- 改动：`mqtt_client_wrapper.c` 新增订阅缓存数组 `s_sub_topics[8]`；`MQTT_EVENT_CONNECTED` 分支（:256）循环 `esp_mqtt_client_subscribe` 全部缓存 topic。
- 验证：代码审查——订阅调用位于连接建立路径；真机验证 BLOCKED（无 broker/设备）。

### FW-04（MA-35）订阅范围与 device_id 校验 ✅
- 改动：`main.c:748-755` 订阅串 `snprintf("%s/%s/command/#", PREFIX, s_device_id)` 与 `config/#`（含具体 device_id 变量，无 `+`）；`on_mqtt_command` 增加防御性校验（解析 topic 第 2 段与本机 s_device_id 比对，不一致丢弃并记日志）。
- 验证：`grep -n "command/#" firmware/main/main.c` → `main.c:750`（snprintf 含 `%s` 与 s_device_id）。

### FW-05（MA-04）定时器句柄误传 ✅
- 改动：`main.c:64-68` 新增 `mqtt_start_timer_cb(TimerHandle_t)` 真正以 `NULL` 调用 `mqtt_client_connect(NULL)`；定时器创建使用该回调；删除误导注释。
- 验证：代码中无 `(void(*)(TimerHandle_t))mqtt_client_connect` 强转路径（仅 esp_restart 的既有强转保留，其不接收参数语义无害——reboot 不读参数）。

### FW-06（MA-13）NVS 误擦除 ✅
- 改动：离线队列改独立 key（`q_0..q_49` + `q_head`/`q_count` 元数据），flush 逐条 `nvs_erase_key`（:129/:195），broker_url 所在的 fan_mqtt namespace 不再被整体擦除。
- 验证：`grep -rn "erase_all" firmware/components/mqtt_client/` → **0**。

### FW-07（MA-14+15+ADJ-7/12）离线队列与 buffered 重发 ✅
- 改动（四点全部落地，`mqtt_client_wrapper.c`）：
  ① `s_queue_mutex` 在 push（:101）/flush（:173）全程 `xSemaphoreTake` 保护；
  ② 环形 key 复用：满队时 `nvs_erase_key(最旧)` + head 前移，key 直接复用，消除 50-blob 搬移写放大；
  ③ 入队降频：`SENSOR_THROTTLE_S=30`（:40），sensor/fan 类离线 30s 一条，告警不受限；
  ④ flush_one（:151-168）topic 加 `/buffered`、payload 经 cJSON 补 `buffered:true`。
- 验证：`grep -n "buffered" .../mqtt_client_wrapper.c` 命中后缀与标记逻辑（:8/:151/:155/:159 等）。

### FW-08（MA-05）OTA 确认接线 ✅
- 改动：`mqtt_client_wrapper.h` 新增 `mqtt_client_set_connected_cb`；CONNECTED 分支调用回调；`main.c:520-523` `on_mqtt_connected` → `ota_handler_confirm_mqtt()`，`main.c:756` 注册。
- 验证：`grep -rn "ota_handler_confirm_mqtt" firmware/` → main.c:522 为非定义/非声明的真实调用点。

### FW-09（MA-17）OTA TLS 证书 ✅
- 改动：`ota_handler.c:88` `.crt_bundle_attach = esp_crt_bundle_attach`（含 esp_crt_bundle.h）；`sdkconfig.defaults` 增 `CONFIG_MBEDTLS_CERTIFICATE_BUNDLE=y`；删除"证书验证已启用"失真注释（现在为真）。
- 验证：`grep crt_bundle` 命中 ota_handler.c + sdkconfig.defaults（2 文件）。

### FW-10（MA-22）ota/status 进度上报 ✅
- 改动：`ota_handler.c:53` `ota_publish_status(state,pct,msg)`——发布 `fan-controller/{id}/ota/status`（协议 §7 完整字段），downloading 每 1% 变化上报、verifying/success/failed 状态全覆盖；ota CMake 增加 mqtt_client 依赖。
- 验证：grep `ota/status` 命中发布代码；WEB-04 订阅落地（前端 OTAProgress 显示真实进度）。

### FW-11（MA-06）停转告警条件反转 ✅
- 改动：`alert_manager.c:15` `STALL_DUTY_PCT=5`；:163 条件 `s_fan_duty[i] > STALL_DUTY_PCT && s_fan_rpm[i] < stall_rpm`（0 RPM 完全堵转必告警；0% 占空比合法停转除外）；新增 `alert_manager_update_fan_duty()`（main.c tach_monitor_task 每秒喂入）。
- 验证：条件表达式中不存在 `rpm > 0` 前置（grep `rpm > 0` 在 alert_manager.c 为 0）。

### FW-12（MA-18）初始化顺序 ✅
- 改动：`main.c app_main` 重排为：**fan_pwm（[0/7] 最先）→ NVS → flash → tach+curve → LED+alert → 传感器 → OTA+USB console → WiFi/MQTT 最后**；WiFi/MQTT 初始化改错误日志+本地模式运行（`ESP_LOGE ... running in local mode`），删除 abort 路径的 `ESP_ERROR_CHECK`。
- 验证：代码顺序 diff（main.c:676 起 app_main）；wifi/mqtt 调用处均为 `if (err != ESP_OK) ESP_LOGE`。

### FW-13（MA-19）上电安全态 ✅
- 改动：`fan_pwm_init`（LEDC 8 通道 duty=0）位于 app_main 最早（main.c:690 `ESP_ERROR_CHECK(fan_pwm_init())`，任何其它外设/网络初始化之前）；与硬件下拉 H-17 双保险。
- 验证：代码审查——app_main 前几行即 LEDC 初始化。

### FW-14（MA-11）LWT/online 字段补全 ✅
- 改动：online 报文（CONNECTED 分支）与 LWT payload（connect 时 cJSON 构造）补齐协议 §1 字段；`mqtt_client_set_status_info(fw_version, ip)` 由 WiFi GOT_IP 注入。
- 验证：与 protocol.md §1 逐字段比对表：

  | 字段 | 协议 §1.1 online | 实现（mqtt_client_wrapper.c:265-276） | 协议 §1.2 LWT | 实现（connect） |
  |---|---|---|---|---|
  | timestamp | ✓ | ✓ time(NULL) | ✓ | ✓ time(NULL)（连接时刻） |
  | device_id | ✓ | ✓ s_device_id | ✓ | ✓ |
  | status | "online" | ✓ | "offline" | ✓ |
  | firmware_version | ✓ | ✓ s_fw_version（FW_VERSION v1.0.1） | — | — |
  | ip_address | ✓ | ✓ s_ip_address | — | — |
  | uptime_seconds | ✓ | ✓ esp_timer 换算 | — | — |

### FW-15（MA-12+ADJ-1）timestamp 语义 ✅
- 改动：main.c 全部上报点 `time(NULL)`（:58/:124/:143/...共 9 处）。
- 验证：`grep -rn "esp_timer_get_time" firmware/main/main.c firmware/components/mqtt_client/*.c | grep -i timestamp` → **0**（剩余 2 处 esp_timer 为 uptime 语义，合法）。web 侧配合判 `timestamp < 1000000000` → "时间未同步"（WEB-07）。

### AG-02（MB-02）agent main.go 接线 ✅
- 改动：`cmd/agent/main.go` 完整实现：config → MQTT 连接（paho AutoReconnect+ConnectRetry 含重连循环）→ system+GPU collectors 按 `monitor.interval` 周期发布 `system-monitor/{hostname}/sensor/{gpu|system}`（hostname=`os.Hostname()`）→ 订阅 `fan-controller/+/sensor/#` 与 `+/alert`（告警转发系统日志 log.Printf=journal）→ SIGTERM/SIGINT 优雅退出（stop ticker + Disconnect）。USB relay 改 `--relay` 可选标志默认关闭（AG-08）。
- 验证：`GOOS=linux go build ./...` 通过；Linux 实机运行验证 BLOCKED（本机 Windows）。

### HA-01（MD-01）占位 device_id 机制 ✅
- 改动：`ha/*.yaml` 全部 topic 改 `__DEVICE_ID__`（含 device identifiers `fan_ctrl___DEVICE_ID__`）；DS18B20 实体另用 `__DS_ADDR_0__`/`__DS_ADDR_1__`；`ha/README.md` 重写为"获取 device_id（订阅 status topic 或看启动日志）+ sed 批量替换"安装步骤，并明确警示 FW-04 修复后不替换将失效。
- 验证：`grep -rn "esp32-placeholder" ha/` → **0**；README 含替换说明。

---

## 3. Phase 2 — 协议对齐

### FW-16（ADJ-2/MA-10）alert schema ✅
- 改动：`alert_manager.h:63-66` 新增 `alert_type_to_string`（temperature_high/fan_stall/voltage_abnormal/wifi_disconnected）/`alert_severity_to_string`/`alert_type_sensor`/`alert_type_from_string`；`main.c on_alert`（:137-153）payload 发送协议 §5 完整字段（alert_type 字符串 + severity + sensor）。

### FW-17（ADJ-8/MA-23）per-type 告警状态 topic ✅
- 改动：`main.c:116-131` `publish_alert_state()` 发布 `fan-controller/{id}/alert/{type}/state` payload `{active, severity, timestamp}`；on_alert 触发时 active:true、on_alert_clear 恢复 active:false；`alert/cleared` topic 发布代码删除；`alert` 事件 topic 保留（web 消费）。
- 验证：`grep -rn "alert/cleared" firmware/ docs/protocol.md` → **0**。

### FW-18（ADJ-6）ds18b20 address/valid ✅
- 改动：`ds18b20.h/c` 新增 `ds18b20_address_str()`（ROM→"28-xxxxxxxxxxxx"）；`main.c:560-573` 上报改为 `address`+`valid`+`temperature_c`，**无效读数不再跳过**（valid:false 一并上报）。
- 配套：HA 按 address 匹配（HA-04）、web types 更新（WEB 侧）。

### FW-19（ADJ-7）上报频率 ✅
- 改动：`main.c:598` `slow_tick % 5` —— voltage 与 internal_temp 5s 周期（电源仍 1s 读取以保断电检测窗口，仅遥测降频）；bme280/ds18b20 维持 1s。

### FW-20（ADJ-9/MA-09/MA-20/ADJ-5）命令处理器补全 + 曲线持久化 ✅
- 改动（五点全部落地，main.c + fan_curve.c）：
  ① `command/curve` handler（handle_curve_command，:175-235）：解析 §4.2 schema——points 数组、PID 平铺字段、`temperature_source` 字符串经 `fan_curve_temp_source_from_str()`（fan_curve.c:50，ADJ-5 四值枚举）映射源编号；
  ② `fan_curve_set_lut/set_pid/set_temp_source` 全部接入 `save_fan_cfg()`（fan_curve.c:64，复用 flash_storage storage_write_config，fan_cfg namespace），init 时 `load_fan_cfg()` 恢复（:89/:193）；
  ③ `command/reset`（main.c:416-425）：无 `confirm:true` 忽略+日志，有则 `wifi_manager_factory_reset()`（FW-28）+重启；
  ④ `config/alert`（main.c:236-356）：订阅 `config/#`，set 解析 rules→`alert_manager_set_thresholds`→`save_alert_cfg_to_nvs`，get（`{"get":true}`）回读发布；启动时 `load_alert_cfg_from_nvs()` 恢复（:711）；
  ⑤ fan_index 越界（≥8）与 duty 越界（>100）直接丢弃并 ESP_LOGW（:396-403）。
- 验证：smoke 测试新增 CP13-CP15 用例覆盖（TST-04）。

### FW-21（MA-16）fan state 补 mode 字段 ✅
- 改动：`fan_curve.h` 新增 `fan_curve_is_manual()`；`main.c:65` payload 补 `mode`（"auto"/"manual"）。

### FW-22（ADJ-11）console 命令扩展 ✅
- 改动：`main.c:460-517` 新增 `fan <0-7> <duty 0-100>`（越界返回 usage 错误）、`wifi status|reset`、`mqtt status|set <url>`（scheme 校验 mqtt:// mqtts://）；:726-728 注册；帮助文本由 help 命令动态生成（7 命令）。
- 验证：console help 输出与 deploy.md/assembly.md 示例一致（DOC-02 同步后）。

### WEB-03（MC-03/ADJ-13）风扇数量 ✅
- 改动：`types.ts:7` 导出 `FAN_COUNT = 8`；`mqtt.ts` fans 数组 `length: FAN_COUNT`、`idx < FAN_COUNT`；前端页面遍历 device.fans（后端 8 元素）→ History 8 序列/Fans 8 卡片自动覆盖。
- 验证：`grep -rn "length: 4\|idx < 4" web/backend/src/` → **0**。

### WEB-04（MC-04+ADJ-12）订阅补齐 ✅
- 改动：`mqtt.ts:60-66` 订阅改 `sensor/#`（吃到 `/buffered` 五级 topic，parts[4]=='buffered' 同 schema 解析）+ 新增 `+/ota/status`；`device.ota` 缓存经 WebSocket 推送；前端 OTAProgress（Devices 页）显示真实 state/progress_pct/message。

### WEB-05（MC-05/MC-06/ADJ-4/ADJ-5）命令与 schema 对齐 ✅
- 改动：① alert 端点改发 `config/alert`（`publishConfig` 新增，协议 §6.2），并加 `POST /:id/alert/get` 回读端点；② CurveSchema pid 平铺（kp/ki/kd/setpoint_c 顶层 optional）；③ `temperature_source: z.enum(['bme280','ds18b20_0','ds18b20_1','internal'])`。
- 验证：非法源 `{"temperature_source":"gpu"}` → HTTP 400（smoke CP13b 用例）。

### WEB-06（MC-11/ADJ-2）告警严重度上色 ✅
- 改动：`Alerts.tsx:11-15` `SEV_COLORS` 键由 alert_type 数字改 severity 字符串（warning=amber/critical=red/normal=green）；时间戳列改 fmtTime（含时间未同步判断）。
- 效果：温度 critical 告警不再显示绿点。

### WEB-07（MC-12/ADJ-1）History 页 ✅
- 改动：8 路 RPM 序列全覆盖（FAN_COUNT=8 条 Line）；`fmtEntryTime/fmtTime` 判 `timestamp < 1000000000` → "时间未同步"。

### WEB-08（MC-13）滑块受控回显 ✅
- 改动：`components/FanCard.tsx:24-32` 两个 useEffect：auto 模式下 `setDuty(fan.pwm_duty_pct)` 同步设备推送、`setMode(fan.mode)` 跟随设备模式切换；拖动结束（onMouseUp/onTouchEnd）提交逻辑保持。

### HA-02（MD-02/ADJ-13）✅
- fans.yaml 生成 **8** 个 fan 实体（Fan 0-7，__DEVICE_ID__ 占位）；ha/README 实体清单改"风扇 0-7"。

### HA-03（MD-03/ADJ-8）✅
- alerts.yaml 四个告警 binary_sensor 改订阅 `alert/{type}/state`（temperature_high/fan_stall/voltage_abnormal/wifi_disconnected 各自独立 retained topic），模板 `{{ 'ON' if value_json.active else 'OFF' }}`——互不干扰；保留 online 实体。

### HA-04（MD-04/ADJ-6）✅
- sensors.yaml DS18B20 两实体按 `address` 匹配（selectattr('address','eq','__DS_ADDR_N__')，未找到输出 unavailable，消除索引移位）；补第二探头实体与 3.3V 电压实体。

### HA-05（MD-05）✅
- fans.yaml/alerts.yaml/sensors.yaml 全部实体补 `availability_topic = fan-controller/{id}/status` + `availability_template`（LWT 联动）。

### DOC-01（ADJ-1~14 汇总/MF-06）protocol.md 集中修订 ✅
- 版本 v1.0 → **v1.0.1**（2026-08-25）。逐条对应裁决表：
  - ADJ-3：§7 OTA topic → `command/ota`，topic 表同步，标注旧写法废止
  - ADJ-8：§5 拆为 5.1 事件 topic（web 消费）/5.2 per-type 状态 topic（HA 消费，retained，payload {active,severity,timestamp}）；topic 表新增两行
  - ADJ-5：§4.2 temperature_source 枚举 4 值 + LUT 严格递增/上限 10 说明
  - ADJ-9：§6 标注 wifi/mqtt "规划中，现行经 USB console 配置"；§6.2 alert 双阈值示例
  - ADJ-10：§8 标题与导语标注"规划中，未实现"；§9.1 启动流程图删除 Discovery 行；§11 HA 侧改手动 packages 口径
  - ADJ-13：{index} 0-7
  - ADJ-14：§5.2 阈值表（75/80、10.8-13.2、±0.25、±0.165、duty>5%+<200RPM、60s）
  - ADJ-1：§1.2 增加 timestamp 语义说明（Unix 秒 + 未同步判断口径）
  - ADJ-6：§12 修订记录确认 ds18b20 address/valid 口径
  - §12 新增 v1.0.1 修订记录（列出全部变更）
- 验证：`grep -rn "alert/cleared" firmware/ docs/protocol.md` → 0；OTA 章节与固件/web/deploy 三方 topic 一致（deploy.md:217 `command/ota`）。

### DOC-02（MF-04）操作文档命令对齐 ✅
- deploy.md §1.4 命令示例改为 FW-22 真实命令集（fan/wifi/mqtt 用法，删除不存在的 `fan 0 speed 75`/`fan 0 auto`，补恢复 auto 的正确方法）；hardware-assembly.md 验收示例同步（`fan 0 50`、wifi status、help 输出 7 命令）。

---

## 4. Phase 3 — 健壮性与清理

### 固件 minors
- **FW-23（MA-08）** ✅：fan_pwm.c 软启动改**常驻控制器任务**（softstart_controller_task:34）+ 目标值数组 s_target_pct + 互斥——所有 LEDC 写入串行化于单任务，消除"每次 set_duty 派生任务"竞态。
- **FW-24（MA-24）** ✅：ds18b20.h/.c 头注释改 bit-bang 如实描述（RMT 迁移标注为可选优化）；README 硬件表声明"不支持寄生供电"。
- **FW-25（MA-25）** ✅：alert_manager.c:173 `if (!any_stall) clear_rule(ALERT_TYPE_FAN_STALL)`——恢复时补 clear 分支。
- **FW-26（MA-26）** ✅：sensor_task 中温度告警输入 = max(BME280, DS18B20 有效读数)（main.c:576-581，实现取简=三源最大值）。
- **FW-27（MA-27）** ✅：`s_wifi` 初值改 `false`（alert_manager.c:38），从未联网也能报 wifi_disconnected。
- **FW-28（MA-28）** ✅：`wifi_manager_factory_reset()` = 清 WiFi 凭据（fan_ctrl）+ `storage_factory_reset()`（fan_cfg 曲线/告警 + fan_mqtt broker/队列，flash_storage.c 新增）；按键 10s、`wifi reset`、`command/reset` 三入口统一调用。
- **FW-29（MA-29）** ✅：AP portal 加 4 位随机确认码（esp_random 生成，串口日志醒目打印，表单必填 code 字段，不匹配拒绝保存）；README 按键行声明该限制。
- **FW-30（MA-30）** ✅：bme280 calib 读取全部 `ESP_RETURN_ON_ERROR` fail-fast（T/P 24 字节、H1、H2-H6）；删除"出错后重初始化"虚假注释。
- **FW-31（MA-31）** ✅：publish_fan_state 中 `char payload[128]` 死代码与 `(void)payload` 删除。
- **FW-32（MA-32）** ✅：partitions.csv factory 0x100000→**0x180000**（与 ota_0/1 同尺寸，后续偏移全部重排：ota_0@0x1A0000 / ota_1@0x320000 / storage@0x4A0000 / coredump@0x4E0000）；sdkconfig 启用 `CONFIG_ESP_COREDUMP=y` + `TO_FLASH`（对应 coredump 分区）。
- **FW-33（MA-33）** ✅：`fan_curve_set_lut` 校验 temp_c 严格递增（fan_curve.c:250-258，乱序拒绝 ESP_ERR_INVALID_ARG + 日志）；duty>100 亦拒绝。
- **FW-34（MA-34 Info）** ✅（选择实施）：mqtt wrapper `handle_event_data` 分片重组——`current_data_offset/total_data_len` 判断，静态缓冲拼装完整后 dispatch（不再截断大 payload）。

### agent
- **AG-03（MB-03）** ✅：`agent.service` 删除，新建 `smart-fan-agent.service`（install.sh/Makefile 引用 `${BINARY}.service` 天然一致）；仓库内无残留 `agent.service` 引用（grep 验证）。
- **AG-04（MB-04）** ✅：client.go 订阅 `fan-controller/+/sensor/#` 与 `+/alert`（协议 §11），删除 command/# 订阅；发布 topic 用 hostname（AG-02 落地）。
- **AG-05（MB-05）** ✅：service 增加 `SupplementaryGroups=dialout`；删除与实际不符的 `ReadWritePaths`（agent 不写文件系统，仅 journal）。
- **AG-06（MB-06）** ✅：config.go 删除 `Port` 字段（合并进 broker URL，yaml 同步 `mqtt://host:1883`）；`validate()` 校验 scheme 前缀（mqtt/mqtts/ws/wss）；补默认值。
- **AG-07（MB-07）** ✅：`if !token.WaitTimeout(30s) || token.Error() != nil` 修正。
- **AG-08（MB-08）** ✅：relay.go `Open()` 有限次重试（5 次，上限 30s 退避）后返回错误；ReadLoop 重连失败退出并记日志；`--relay` 标志默认关闭（main.go）；头注释改为如实定位（调试桥，不承诺"读 ESP32 JSON 上报"）。

### web
- **WEB-09（MC-07）** ✅：deploy.md 末尾新增"Web 层安全声明"（0.0.0.0 + CORS 全开 + 无鉴权的局域网假设；禁止公网暴露；VPN/反代建议；token 鉴权为规划项）。未加 token（不强制）。
- **WEB-10（MC-08）** ✅：决定：**标注"未接通"**——history 端点响应含 `stub: true, note: 'not wired: ...'`；History 页面顶部提示"设备 Flash 历史导入为规划功能（后端 /history 端点未接通）"。
- **WEB-11（MC-09/ADJ-14）** ✅：7 个死组件全部复活并成为唯一实现——pages/Dashboard 用 DeviceCard（+TemperatureGauge/VoltageBar），pages/Fans 用 FanCard+CurveEditor，pages/Alerts 用 AlertRuleEditor，pages/Devices 用 OTAProgress；全部内联版删除（两套实现不再分叉）；AlertRuleEditor 改双阈值模型（温度 warn/crit、12V min/max、stall、wifi timeout）。
- **WEB-12（MC-10）** ✅：CurveEditor 输入 clamp（duty `Math.max(0,Math.min(100,round))`、温度 min/max 属性）、点位按温度排序展示与提交（sortPoints）、点数上限 10（`MAX_POINTS`，+点按钮达限禁用、可删点）。

### test
- **TST-02（ME-02）** ✅：integration T4 重写——先订阅捕获 payload → 发布 → 断言 `fan_index/duty_pct/mode` 三字段；删除创建后未读的 T_OUT（改为实际消费）；T3 顺带补 pwm_duty_pct/rpm/mode 字段断言。
- **TST-03（ME-03）** ✅：smoke 头部删除未用的 jq 依赖声明；CP7 补 SUB_OUT 内容断言（`"duty_pct":75`）；CP12 TOPICS 计算修正（`\*\*Topic\*\*:` + topic 模板行双口径）；两脚本头部注明"必须从仓库根运行"。
- **TST-04（ME-04）** ✅：smoke 新增 5 组用例：CP13 curve 命令字段断言 + CP13b 非法源 400；CP14 reset 语义（协议文档确认 + confirm:false 发布链路）；CP15 config/alert 双阈值 payload 捕获；CP16 ota/status 进度→REST 缓存断言；CP17 buffered 五级 topic 经 sensor/# 摄取断言。运行时验证 BLOCKED（无 broker），bash -n 通过。

### docs 与仓库根
- **DOC-03（MF-01/02/05）** ✅：README——4路→8路（badge/架构图/特性表/硬件表/Web 控制台节）、PCB 80×60 双层→99×99mm 4 层、console 命令数如实（7 命令）、Unity 测试数如实（13 文件 + 未接入构建说明）、`npm test` 修正为真实构建命令（backend/frontend npm run build，明确无 jest 套件）、冒烟预期 PASS=25；docs/index.html 同步（8 路/99×99 4 层/packages 口径）。
- **DOC-04（MF-03/ADJ-10）** ✅：README/ha/README 删除"自动发现/无需手动配置"承诺；改为"手动 packages（ha/ 目录）+ Discovery 规划中"。验证：`grep -rn "自动发现" README.md ha/README.md` 4 处命中全部带"规划中/不实现"限定语（§6.2 门允许）。
- **DOC-05（MF-08）** ✅：`git rm -r --cached .omo .sisyphus`（74 个文件移出跟踪，本地文件保留）；`.gitignore` 增加 `.omo/`、`.sisyphus/`、`.claude/`、`*.bak`、`*.v7backup`（H-15 连带）；`git check-ignore` 确认生效。
- **DOC-06（MF-05 连带）** ⚠️ **DESCOPE**：`firmware/test/` 13 个 Unity 测试**未接入** idf.py 构建。采用计划允许的降级路径（"允许降级为 README 如实标注未接入构建并在 changelog 登记 DESCOPE"）：README 已如实标注。整改执行阶段尚未取得 ESP-IDF 环境；后续环境补齐后已验证产品固件构建，但 Unity 测试接入及 8 路断言更新仍超出 P2 预算。

---

## 4.5 构建期补充修复（idf.py build 实测发现的既有缺陷）

> 这些问题在静态审查中不可见（原固件从未编译通过，MA-01/MA-02 佐证），构建实测后修复。
> 均为"让构建成立"的最小改动，未改变整改项行为语义。

| # | 问题 | 修复 |
|---|---|---|
| B1 | `cJSON` 不是 IDF v5.3 组件名（内置组件名为 `json`，头文件仍为 cJSON.h） | main/mqtt_client/usb_console/ota_handler 的 REQUIRES `cJSON` → `json` |
| B2 | TinyUSB 在 IDF v5.x 已移出主树（组件仓库 `espressif/esp_tinyusb`） | usb_console 新增 `idf_component.yml`（esp_tinyusb ^2.0.0）；API 对齐 v2.0：头文件 `tinyusb_cdc_acm.h` + `TINYUSB_DEFAULT_CONFIG()` 宏 + `tinyusb_cdcacm_init`（旧名 `tusb_cdc_acm_init`）+ 删除已移除的 `.usb_dev`/`.rx_unread_buf_sz` 字段（缓冲由 `CONFIG_TINYUSB_CDC_RX_BUFSIZE` 控制，sdkconfig 已设 512） |
| B3 | `status_led.c` 使用的 `rmt_write_symbols()` 在 IDF v5.x RMT 驱动中不存在 | 改用官方 copy encoder 方案（`rmt_new_copy_encoder` + 直接发送 `rmt_symbol_word_t` 数组），动画逻辑不变 |
| B4 | `ESP_RETURN_ON_ERROR` 定义在 `esp_check.h`（非 esp_err.h），9 个组件缺 include | bme280/fan_tach/fan_pwm/power_monitor/flash_storage/mqtt_client/status_led/usb_console/wifi_manager 全部补 `#include "esp_check.h"` |
| B5 | 跨组件 `#include "X/X.h"` 在 IDF 组件模型下无法解析（组件 INCLUDE_DIRS 只暴露自身目录） | 统一为 IDF 惯例平铺 include `X.h`（main.c 13 处、fan_curve 2 处、wifi_manager/ota_handler 各 1 处，另加 main.c/ota_handler 的 mqtt_client_wrapper.h 2 处） |
| B6 | `esp_timer` 不属于公共依赖集，flash_storage/mqtt_client/main 的 REQUIRES 缺失；wifi_manager.c 用 esp_timer_get_time 未 include 头文件 | 三处 CMakeLists 补 `esp_timer`；wifi_manager.c 补 `#include "esp_timer.h"`；ota_handler.c 补 cJSON.h include（进度上报用 cJSON） |

**⚠ 待裁决登记（E4 规则）**：`CONFIG_ESP_CONSOLE_USB_SERIAL_JTAG=y`（硬件清单 H-03 要求）与
usb_console 的 TinyUSB CDC-ACM 同用 GPIO19/20 —— ESP32-S3 的 USB-Serial-JTAG 与 USB-OTG
两外设共享同一 USB PHY，运行期只能二选一，两份整改清单均未覆盖此冲突。当前按 H-03 字面要求
保留该配置（构建通过；真机验证时需裁决：日志走 USJ + 命令走 OTG 是否互斥；若互斥，候选方案为
`CONFIG_ESP_CONSOLE_USB_CDC`（日志走 TinyUSB CDC）或砍掉其一）。

---

## 5. BLOCKED 清单（环境缺失，不推断结果）

| 项 | 原因 | 已完成的替代验证 |
|----|---|---|
| ~~`cd firmware && idf.py build`~~ | ~~本机无 ESP-IDF~~ **已解除**：用户提供 D:\espressif（v5.3.5）后实测构建通过 | ✅ 见 §8：bin 0x11EA90 / 分区余 25%；构建期发现的 6 类问题已修复（§4.5） |
| 真机/模拟 broker 冒烟（smoke_test.sh 完整跑通 + integration_test.sh） | 本机无 mosquitto 客户端与 broker | `bash -n` 两脚本语法通过；用例逻辑静态审查；用例覆盖 TST-04 全部目标 topic |
| agent Linux 实机运行（mosquitto_sub 收数） | 本机 Windows | `GOOS=linux go build/vet` 通过 |

---

## 6. DESCOPE 清单

| 项 | 内容 | 理由 | 恢复路径 |
|----|---|---|---|
| DOC-06 | firmware/test 13 个 Unity 测试未接入 idf.py 构建 | 产品固件已构建通过；测试组件接入+断言更新到 8 路超出 P2 预算（计划明文允许降级） | 按 ESP-IDF 测试组件规范接入，断言更新 FAN_PWM_COUNT=8 等 |

（FW-34 分片重组选择**实施**而非 DESCOPE。）

---

## 7. 发现→整改项映射表（75 条销号状态）

### A：firmware（35 条）

| 发现 | 去向 | 状态 | 发现 | 去向 | 状态 |
|---|---|---|---|---|---|
| MA-01 | FW-01 | ✅ | MA-19 | FW-13 + 硬件 H-17 | ✅ |
| MA-02 | FW-02 | ✅ | MA-20 | FW-20 | ✅ |
| MA-03 | FW-03 | ✅ | MA-21 | 硬件 H-03（v1.2.1） | ✅ |
| MA-04 | FW-05 | ✅ | MA-22 | FW-10 | ✅ |
| MA-05 | FW-08 | ✅ | MA-23 | FW-17（ADJ-8） | ✅ |
| MA-06 | FW-11 | ✅ | MA-24 | FW-24 | ✅ |
| MA-07 | 硬件 H-03（v1.2.1） | ✅ | MA-25 | FW-25 | ✅ |
| MA-08 | FW-23 | ✅ | MA-26 | FW-26 | ✅ |
| MA-09 | FW-20 | ✅ | MA-27 | FW-27 | ✅ |
| MA-10 | FW-16（ADJ-2） | ✅ | MA-28 | FW-28 | ✅ |
| MA-11 | FW-14 | ✅ | MA-29 | FW-29 | ✅ |
| MA-12 | FW-15（ADJ-1） | ✅ | MA-30 | FW-30 | ✅ |
| MA-13 | FW-06 | ✅ | MA-31 | FW-31 | ✅ |
| MA-14 | FW-07 | ✅ | MA-32 | FW-32 | ✅ |
| MA-15 | FW-07 + WEB-04 | ✅ | MA-33 | FW-33 | ✅ |
| MA-16 | FW-21 | ✅ | MA-34 | FW-34（分片，已实施）+ 硬件 H-03（console 路由） | ✅ |
| MA-17 | FW-09 | ✅ | MA-35 | FW-04 | ✅ |
| MA-18 | FW-12 | ✅ | | | |

### B：agent（8 条）——MB-01→AG-01 ✅｜MB-02→AG-02 ✅｜MB-03→AG-03 ✅｜MB-04→AG-02/AG-04 ✅｜MB-05→AG-05 ✅｜MB-06→AG-06 ✅｜MB-07→AG-07 ✅｜MB-08→AG-08 ✅

### C：web（13 条）——MC-01→WEB-02 ✅｜MC-02→WEB-01 ✅｜MC-03→WEB-03 ✅｜MC-04→WEB-04 ✅｜MC-05→WEB-05 ✅｜MC-06→WEB-05 ✅｜MC-07→WEB-09 ✅｜MC-08→WEB-10 ✅｜MC-09→WEB-11 ✅｜MC-10→WEB-12 ✅｜MC-11→WEB-06 ✅｜MC-12→WEB-07 ✅｜MC-13→WEB-08 ✅

### D：ha（5 条）——MD-01→HA-01 ✅｜MD-02→HA-02 ✅｜MD-03→HA-03 ✅｜MD-04→HA-04 ✅｜MD-05→HA-05 ✅

### E：test（4 条）——ME-01→TST-01 ✅｜ME-02→TST-02 ✅｜ME-03→TST-03 ✅｜ME-04→TST-04 ✅

### F：docs 与仓库根（10 条）——MF-01→DOC-03 ✅｜MF-02→DOC-03 ✅｜MF-03→DOC-04（ADJ-10）✅｜MF-04→FW-22+DOC-02 ✅｜MF-05→DOC-03+DOC-06（DOC-06 DESCOPE，已登记）⚠️✅｜MF-06→DOC-01（ADJ-3）✅｜MF-07→硬件 H-07 承接 ✅（文档层 2026-08-26 完成，见 hardware/docs/changelog-v1.2.md）｜MF-08→DOC-05 ✅｜MF-09→硬件 H-16 ✅（并入指南 v1.2 重写）/ H-06 待原理图（hardware/BOM.csv 仍为旧口径，配单前必须等 BOM v1.2 定稿）｜MF-10→不修（Info）✅

> 75 条中 2 条（MF-07/MF-09）按映射表由硬件清单承接，不属于本清单销号范围；其余 73 条全部由本清单项目销号（含 1 条 DESCOPE 登记）。

---

## 8. 构建矩阵实测（2026-08-25）

| 命令 | 结果 |
|---|---|
| `cd firmware && idf.py build` | ✅ **通过**（ESP-IDF v5.3.5；`Project build complete`，smart-fan-controller.bin = 0x11EA90 字节，最小 app 分区 0x180000 余 25%；bootloader 0x5990） |
| `cd agent && GOOS=linux go build ./... && go vet ./...` | ✅ 通过；go.sum 16 条已入库 |
| `cd web/backend && npm ci && npm run build` | ✅ `dist/server.js` 存在 |
| `cd web/frontend && npm ci && npm run build` | ✅ `dist/index.html`（0.57 kB）+ assets 产出 |
| `bash -n test/smoke_test.sh test/e2e/integration_test.sh` | ✅ 通过 |
| `python -c "import yaml,glob; ..."` | ✅ ha/*.yaml 全部合法 |

## 9. grep 门实测（§6.2 全量）

```
((PASS++)) test/                          = 0 ✅
esp32-placeholder ha/                     = 0 ✅
length: 4|idx < 4 web/backend/src/        = 0 ✅
FAN_PWM_COUNT 4|FAN_CURVE_FANS 4|fan_rpm[4] firmware/ = 0 ✅
CONSOLE_UART firmware/sdkconfig.defaults  = 0 ✅
erase_all firmware/components/mqtt_client/ = 0 ✅
esp_timer_get_time main.c | grep -i timestamp = 0 ✅
alert/cleared firmware/ docs/protocol.md  = 0 ✅
esp32-XXXXXX/command/ota docs/deploy.md   = 0 ✅
自动发现 README.md ha/README.md           = 4 处，全部带"规划中/不实现"限定 ✅
（H-03 8 条门见 §1 Phase 0-7，全部 0/符合）
```

---

**版本：** v1.2（2026-08-25）
**执行依据：** `docs/module-remediation-plan-v1.2.md` v1.2
**配套交付物：** `docs/module-recheck.md`（六矩阵复验）

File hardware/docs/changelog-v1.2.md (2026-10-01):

# 硬件整改销号日志 v1.2（changelog-v1.2）

> 依据：`hardware/docs/remediation-plan-v1.2.md`（v1.2.2）。
> 记录硬件侧整改项 H-01~H-17 的完成状态与验证证据。执行日期：2026-08-25 ~ 2026-08-26。

---

## 0. 总览

- 状态：H-03/H-04/H-07/H-15/H-16 **完成**；H-01/H-02（原理图/PCB 重绘）由用户在嘉立创 EDA
  手工绘制中（决策 D6）；H-05/H-06/H-08~H-14/H-17 为随图项，待原理图/PCB 完成后验收。

---

## 1. 已完成项

### H-03 固件引脚同步 ✅（2026-08-25，随模块整改完成）
- fan_pwm 8 路 GPIO5-12、fan_tach 8 路 GPIO13(FAN1_TACH)/14/15/21/38/39/40/41（PCNT 4单元×2通道）、
  power_monitor CH_12V=CH0/CH_5V=CH1/CH_3V3=CH3、分压比 6.0/5.7/5.7、LED_GPIO 45、
  BTN_GPIO 47、console 走 USB-Serial-JTAG、五处路数硬编码清理。
- 验证：硬件清单 H-03 的 8 条 grep 全部通过；`idf.py build` 实测通过
  （ESP-IDF v5.3.5，bin 0x11EA90 / 分区余 25%）。证据：`docs/changelog-modules-v1.2.md` §1/§8。

### 计划文档修订 v1.2.2 ✅（2026-08-26）
- 新增决策 D6（嘉立创 EDA 唯一真源 + KiCad 归档 legacy/）；H-01/H-02 目标改嘉立创 EDA；
  H-04/H-07 验收命令修正自噬（排除计划自身/审查档案/legacy）；H-15 改归档口径；
  §5-6 标注固件构建实测通过。

### 旧 KiCad 工程归档 ✅（2026-08-26，配合 D6）
- `hardware/legacy/`：kicad_pro/sch/pcb + 5 个文本 .sch 占位图 + 旧 gerber/ +
  test-v10-format.txt（18 文件 git rename）；`.v7backup` 脱离 git 跟踪（磁盘保留）。
- 验证：`git ls-files hardware/legacy/ | grep -E "bak|v7backup"` → 0。

### H-04 扩展板矛盾清理（文档层）✅（2026-08-26）
- 动作：design-guide 重写为 v1.2（扩展板全部改为 D1 口径：成品板独立 SATA 供电、
  接一路风扇座、无专用电路/信号/固件逻辑，建议 Fan8/J10）；checklist 第 8 节改 D1 口径；
  删除"扩展板专用 PWM 信号经某 GPIO 缓冲输出"行、"扩展板 PH2.0 12V 供电"行、"扩展板特殊固件逻辑"等全部表述。
- 验证（v1.2.2 修正后的验收命令）：
```bash
grep -rn "EXT_PWM" hardware/docs/ --exclude=remediation-plan-v1.2.md            # 空 ✓
grep -rn "GPIO13" hardware/docs/ --exclude=remediation-plan-v1.2.md | grep -v "FAN1_TACH"   # 空 ✓
# GPIO13 仅以 FAN1_TACH 身份出现（design-guide-v1.2.md 与 checklist 的 Tach 引脚行）
grep -rn "扩展板" hardware/docs/ --exclude=remediation-plan-v1.2.md | grep "12V\|供电\|PWM"
# 命中均为 D1 口径表述（"独立 SATA 供电"），人工确认无"主控板给扩展板供电" ✓
```

### H-07 全部文档同步 ✅（2026-08-26，文档层）
- `hardware-design-guide-v1.2.md`（新）：8 路、99×99mm 4 层（L2 完整 GND/L3 电源）、
  GPIO v1.2 权威表镜像（ADC=GPIO1/2/4、WS2812=GPIO45、按键=GPIO47、屏幕=GPIO42/43/44/48）、
  电源架构（F1≥3A、D2/D3 二极管或）、Tach 网络 3R+1nF×8、PWM 下拉×8、USBLC6 VCC=+5V、
  载流按 IPC-2150（12V 走 L3 铺铜；旧"2mm=6A"错误表述废除）、J13 定义、
  嘉立创免费档工艺、EDA 操作流程。
- `schematic-review-checklist.md`（v1.2）：引脚表与计划 §1 对齐；新增 PWM 下拉/OE 全接地/
  USBLC6 VCC/F1 选型/GPIO35-37 NC 等检查项；常见错误速查更新（10 条致命错误）。
- `docs/hardware-assembly.md`（v1.2 重写）：BOM 核心件表更新（U3×2、J3~J10×8、F1≥3A、
  D2/D3、U5 USBLC6、J11/J12、J13）；焊接顺序按 v1.2 位号重排；
  **删除不存在的 TVS 器件焊接表述**（旧文把不存在的器件型号列为 D3/D4~D8；Step 2 改为焊 U5 USBLC6 + D3 B5819W）。
- README.md / docs/index.html 的路数与板卡口径：已于模块整改 DOC-03 完成（2026-08-25）。
- v1.1 旧文档处置：`hardware-design-guide-v1.1.md`、`bom-main-board-v1.1.md`
  → `git mv` 至 `hardware/legacy/docs/`（选择"归档"路径，登记于此）。
- 验证（v1.2.2 修正后的验收命令）：
```bash
grep -rn "100×70\|100x70" hardware/ docs/ README.md \
  --exclude-dir=legacy --exclude=remediation-plan-v1.2.md            # 空 ✓
grep -rn "GPIO21.*ADC\|GPIO35.*ADC\|GPIO36.*ADC\|ADC.*GPIO21\|ADC.*GPIO35\|ADC.*GPIO36" hardware/ docs/ \
  --exclude-dir=legacy --exclude=remediation-plan-v1.2.md --exclude=module-review-plan.md \
  --exclude=module-review-report.md                                   # 空 ✓
grep -rn "6 路\|6路" hardware/docs/ README.md \
  --exclude=remediation-plan-v1.2.md --exclude=module-review-plan.md --exclude=module-review-report.md   # 空 ✓
```

### H-16 清理文档死链接 ✅（2026-08-26，并入指南 v1.2 重写）
- v1.1 指南附录引用的 `bom-*.xlsx`、`pcb-layout-example.png`、`test-procedure.md` 均不存在；
  v1.2 指南附录已改为指向实际存在的仓库文件（remediation-plan / checklist / changelog / BOM v1.2）。

---

## 2. 待完成项（依赖原理图/PCB，用户在嘉立创 EDA 绘制中）

| 项 | 内容 | 依赖 | 验收要点 |
|----|---|---|---|
| **H-01** | 嘉立创 EDA v1.2 原理图（存 `hardware/lceda/`） | 用户绘制 | ERC 0/0；对照 checklist v1.2 全勾；无占位内容 |
| **H-02** | v1.2 PCB（99×99/4层/L2 GND/L3 12V 铺铜） | H-01 | DRC 0；keepout 存在；4×M3 安装孔 |
| **H-05** | USB/SATA 倒灌防护（D2/D3 二极管或） | 随 H-01 | VBUS 网络仅连 J2/USBLC6/D3 阳极 |
| **H-06** | BOM v1.2（md + 重写 hardware/BOM.csv + 位号对照表） | 随 H-01 | 位号集合==原理图；F1 含 ≥3A；csv 与 md 一致。**当前 hardware/BOM.csv 仍为旧口径，配单前必须等本项** |
| **H-08** | USBLC6 VCC=+5V | 随 H-01 | U5 Pin5 网络=+5V |
| **H-09** | 74AHCT125 使能/去耦完整 | 随 H-01 | 8 个 OE 全接 GND、VCC 各 100nF |
| **H-10** | F1 选型与 12V 载流 | 随 H-02/H-06 | BOM F1 ≥3A；12V 为 L3 铺铜 |
| **H-11** | Tach 网络补齐 | 随 H-01 | 每路 3R+1nF ×8；BOM 24+8 |
| **H-12** | SPI_CS 上拉与 strapping 标注 | 随 H-01 | GPIO44 10k 上拉；GPIO3/46 标 NC |
| **H-13** | AMS1117 热设计 | 随 H-02 | 散热 ≥4cm² + 过孔阵列 |
| **H-14** | WS2812 串阻 33~100Ω | 随 H-01 | BOM 含 1 只 |
| **H-17** | PWM 输入线下拉 10kΩ×8 | 随 H-01 | 原理图 8 个 PWM 网络各有下拉 |

（固件侧配套已全部就绪：FW-13 app_main 最早 LEDC duty=0，与 H-17 双保险。）

---

## 2.5 KiCad 参考稿（2026-09-06，非权威，D6 不变）

- 应用户要求，agent 用 KiCad 10 平行绘制一份 v1.2 原理图作**对比参照**：
  `hardware/kicad-reference/`（.kicad_sch + .kicad_pro + PDF 导出 + 网表 + 生成器脚本）。
- 定位：对比参照，**非权威**——嘉立创 EDA 工程仍是唯一真源；禁止用于配单/打样。
- 验证：KiCad 10.0.5 ERC 实测 **0 Errors / 11 Warnings**（10×74AHCT125 展平嵌入的
  外观性差异 + 1×BME280 SDO→GND 有意设计）；网表抽查全部网络与计划 §1 一一对应。
- 生成方式与差异说明见该目录 README.md。

## 2.6 嘉立创 EDA 参考稿（2026-09-06，非权威，D6 不变）

- 应用户要求通过 EasyEDA Pro API（run-api-gateway 扩展 + WebSocket 桥接）完成一次嘉立创版：
  本地工程 **SmartFan-v1.2-ref**（`C:\Users\OneAs\Documents\LCEDA-Pro\projects\`）。
- **原理图完整**：A0 页 95 个元件（位号/名称/全部引脚网络标签+电源标志），网络命名与
  remediation-plan §1 一致；元件选自嘉立创系统库并核实 LCSC 编号（C6186/C7519/C8678 等）。
  详细清单/脚本/注意事项见 `hardware/lceda-ref/README.md`。
- **DRC 修复**：158 致命 → **9 致命 / 320 警告 / 0 错误**（2026-09-07 三轮修复）：
  ① 约 149 个致命 = createNetLabel 图元与引脚无电气连接（网格吸附偏差）→ 改用
  带网络名的短导线（305 根）逐引脚接入；② 9 个致命 = SN74AHCT125D 多子部件
  位号重复/焊盘不对应 → 替换为单部件 74AHCT125D-Q100118（SO-14 同封装）；
  ③ pin.modify({noConnected}) API 未生效 → NC 引脚悬空降为警告级。
  剩余 9 致命需在编辑器中目视拖正标签（网格吸附偏差为 API 限制）。
- **PCB**：转换入口已通（DRC 确认框不再阻塞），等上述 9 致命目视修复后
  执行 Alt+I 导入 → 99×99 板框/四层/手工布线。
- 教训登记：EasyEDA API 的 createNetFlag 不写 Value 属性 → DRC 致命；批量遍历标志图元的
  get() 会触发 API 500；sch 坐标单位 10mil、pcb 单位 1mil。

## 3. 已知待裁决事项

- **USB PHY 互斥**（登记于 `docs/changelog-modules-v1.2.md` §4.5）：`CONFIG_ESP_CONSOLE_USB_SERIAL_JTAG=y`
  （H-03 按硬件清单字面要求）与 usb_console 的 TinyUSB CDC-ACM 共用 GPIO19/20，
  ESP32-S3 两 USB 外设共享 PHY 运行期互斥。真机验证时需二选一；若互斥，候选方案为
  `CONFIG_ESP_CONSOLE_USB_CDC`（日志与命令均走 TinyUSB CDC）。原理图侧 D+/D- 连接不受影响。

---

**版本：** v1.0（2026-08-26）

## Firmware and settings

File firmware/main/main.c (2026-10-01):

/*
 * main.c — Smart Fan Controller 固件主循环（v1.2 整改版）
 * 平台: ESP32-S3-N16R8  框架: ESP-IDF v5.3+
 *
 * 启动顺序（FW-12/FW-13）: LEDC(duty=0 上电安全态) → NVS → Flash →
 *   Tach → 曲线 → LED/告警 → 传感器 → USB console → WiFi/MQTT 最后
 *   （WiFi/MQTT 失败不 abort：记日志、进入本地模式、后台重试）
 */
#include <stdio.h>
#include <string.h>
#include <time.h>
#include <stdlib.h>
#include "freertos/FreeRTOS.h"
#include "freertos/task.h"
#include "freertos/timers.h"
#include "esp_log.h"
#include "esp_timer.h"
#include "esp_system.h"
#include "esp_mac.h"
#include "nvs_flash.h"
#include "cJSON.h"

#include "power_monitor.h"
#include "fan_pwm.h"
#include "fan_tach.h"
#include "bme280.h"
#include "ds18b20.h"
#include "status_led.h"
#include "wifi_manager.h"
#include "mqtt_client_wrapper.h"
#include "usb_console.h"
#include "flash_storage.h"
#include "fan_curve.h"
#include "alert_manager.h"
#include "ota_handler.h"

static const char *TAG = "MAIN";
#define FW_VERSION "v1.0.1"

/* ---- MQTT topic helpers ---- */
static char s_device_id[16] = "esp32-unknown";

static void publish_sensor_json(const char *type, const char *json)
{
    char topic[80];
    snprintf(topic, sizeof(topic), "%s/%s/sensor/%s",
             MQTT_TOPIC_PREFIX, s_device_id, type);
    mqtt_publish(topic, json, 0);
}

/* FW-21: fan state 补 mode 字段；FW-31: 删除死代码 payload 缓冲 */
static void publish_fan_state(uint8_t idx, uint8_t duty_pct, uint16_t rpm, bool stalled)
{
    char topic[64];
    snprintf(topic, sizeof(topic), "%s/%s/fan/%d/state",
             MQTT_TOPIC_PREFIX, s_device_id, idx);
    cJSON *root = cJSON_CreateObject();
    cJSON_AddNumberToObject(root, "timestamp",    (double)time(NULL));   /* FW-15: Unix 秒 */
    cJSON_AddStringToObject(root, "device_id",    s_device_id);
    cJSON_AddNumberToObject(root, "fan_index",    idx);
    cJSON_AddNumberToObject(root, "pwm_duty_pct", duty_pct);
    cJSON_AddNumberToObject(root, "rpm",          rpm);
    cJSON_AddBoolToObject  (root, "stalled",      stalled);
    cJSON_AddStringToObject(root, "mode",
                            fan_curve_is_manual(idx) ? "manual" : "auto");
    char *js = cJSON_PrintUnformatted(root);
    if (js) {
        mqtt_publish(topic, js, 0);
        free(js);
    }
    cJSON_Delete(root);
}

/* ---- WiFi callbacks ---- */
static bool s_wifi_connected = false;
static TimerHandle_t s_mqtt_start_timer = NULL;

/* FW-05: 定时器回调真正以 NULL 调用 mqtt_client_connect（不再把
 * TimerHandle_t 伪装成 broker_url 传参） */
static void mqtt_start_timer_cb(TimerHandle_t t)
{
    (void)t;
    mqtt_client_connect(NULL);   /* NULL → 从 NVS 加载 broker_url */
}

static void on_wifi_connected(const char *ip)
{
    ESP_LOGI(TAG, "WiFi connected: %s", ip);
    s_wifi_connected = true;
    status_led_set_mode(LED_MODE_NORMAL);
    alert_manager_update_wifi(true);
    ota_handler_confirm_network(); /* OTA Phase 2 */
    mqtt_client_set_status_info(FW_VERSION, ip);   /* FW-14: online 报文字段 */

    /* ⚠️ MQTT 启动延迟 500ms（不在事件处理器中直接调用，避免递归互斥锁崩溃） */
    if (!s_mqtt_start_timer) {
        s_mqtt_start_timer = xTimerCreate("mqtt_st", pdMS_TO_TICKS(500),
                                           pdFALSE, NULL, mqtt_start_timer_cb);
    }
    xTimerStart(s_mqtt_start_timer, 0);
}

static void on_wifi_disconnected(void)
{
    ESP_LOGW(TAG, "WiFi disconnected");
    s_wifi_connected = false;
    status_led_set_mode(LED_MODE_WIFI_DISCONNECTED);
    alert_manager_update_wifi(false);
}

/* ---- Alert callbacks ---- */

/* FW-17: per-type retained 状态 topic（ADJ-8），告警触发/恢复时更新 */
static void publish_alert_state(alert_type_t type, bool active,
                                alert_severity_t sev)
{
    char topic[80];
    snprintf(topic, sizeof(topic), "%s/%s/alert/%s/state",
             MQTT_TOPIC_PREFIX, s_device_id, alert_type_to_string(type));
    cJSON *root = cJSON_CreateObject();
    cJSON_AddBoolToObject  (root, "active",    active);
    cJSON_AddStringToObject(root, "severity",
                            active ? alert_severity_to_string(sev) : "normal");
    cJSON_AddNumberToObject(root, "timestamp", (double)time(NULL));
    char *js = cJSON_PrintUnformatted(root);
    if (js) {
        mqtt_publish(topic, js, 1);   /* retain 语义经 QoS1 事件 topic 承载见下 */
        free(js);
    }
    cJSON_Delete(root);
}

static void on_alert(const alert_event_t *ev)
{
    /* Update LED */
    led_mode_t mode = (ev->severity == ALERT_CRITICAL) ? LED_MODE_ERROR : LED_MODE_WARNING;
    status_led_set_mode(mode);

    /* FW-16/ADJ-2: 协议 §5 完整字段 —— alert_type 字符串 + severity + sensor */
    char topic[64];
    snprintf(topic, sizeof(topic), "%s/%s/alert", MQTT_TOPIC_PREFIX, s_device_id);
    cJSON *root = cJSON_CreateObject();
    cJSON_AddNumberToObject(root, "timestamp",  (double)time(NULL));
    cJSON_AddStringToObject(root, "device_id",  s_device_id);
    cJSON_AddStringToObject(root, "alert_type", alert_type_to_string(ev->type));
    cJSON_AddStringToObject(root, "severity",   alert_severity_to_string(ev->severity));
    cJSON_AddStringToObject(root, "message",    ev->message);
    cJSON_AddNumberToObject(root, "value",      ev->value);
    cJSON_AddNumberToObject(root, "threshold",  ev->threshold);
    cJSON_AddStringToObject(root, "sensor",     alert_type_sensor(ev->type));
    char *js = cJSON_PrintUnformatted(root);
    if (js) { mqtt_publish(topic, js, 1); free(js); }
    cJSON_Delete(root);

    /* per-type 状态 topic 同步更新 */
    publish_alert_state(ev->type, true, ev->severity);
}

static void on_alert_clear(alert_type_t type)
{
    if (alert_manager_get_severity() == ALERT_NORMAL)
        status_led_set_mode(LED_MODE_NORMAL);

    /* FW-17: 恢复发布 per-type 状态 topic（旧的独立清除 topic 已删除） */
    publish_alert_state(type, false, ALERT_NORMAL);
}

/* ---- Fan stall callback ---- */
static void on_fan_stall(uint8_t fan_index)
{
    ESP_LOGE(TAG, "Fan %d stalled!", fan_index);
    alert_manager_update_fan_rpm(fan_index, 0);
}

/* ---- MQTT command handler（协议 §4/§6） ---- */

/* FW-20①: command/curve —— LUT points / PID 平铺字段 / temperature_source 字符串 */
static void handle_curve_command(cJSON *root)
{
    cJSON *idx_j = cJSON_GetObjectItem(root, "fan_index");
    if (!idx_j || idx_j->valueint < 0 || idx_j->valueint >= FAN_CURVE_FANS) {
        ESP_LOGW(TAG, "curve: fan_index out of range, dropped");
        return;
    }
    uint8_t fan = (uint8_t)idx_j->valueint;

    cJSON *src_j = cJSON_GetObjectItem(root, "temperature_source");
    if (src_j && src_j->valuestring) {
        int src = fan_curve_temp_source_from_str(src_j->valuestring);  /* ADJ-5 */
        if (src < 0) {
            ESP_LOGW(TAG, "curve: invalid temperature_source '%s', dropped",
                     src_j->valuestring);
            return;
        }
        fan_curve_set_temp_source(fan, (uint8_t)src);
    }

    cJSON *mode_j = cJSON_GetObjectItem(root, "mode");
    const char *mode = (mode_j && mode_j->valuestring) ? mode_j->valuestring : "lut";

    if (strcmp(mode, "lut") == 0) {
        cJSON *pts = cJSON_GetObjectItem(root, "points");
        if (cJSON_IsArray(pts)) {
            int n = cJSON_GetArraySize(pts);
            if (n > 0 && n <= FAN_CURVE_MAX_POINTS) {
                lut_point_t lut[FAN_CURVE_MAX_POINTS];
                for (int i = 0; i < n; i++) {
                    cJSON *p = cJSON_GetArrayItem(pts, i);
                    cJSON *t = cJSON_GetObjectItem(p, "temp_c");
                    cJSON *d = cJSON_GetObjectItem(p, "duty_pct");
                    if (!t || !d) return;
                    lut[i].temp_c   = (float)t->valuedouble;
                    lut[i].duty_pct = (uint8_t)t->valueint;
                }
                if (fan_curve_set_lut(fan, lut, (uint8_t)n) != ESP_OK) {
                    ESP_LOGW(TAG, "curve: LUT rejected (not strictly increasing)");
                }
            }
        }
        fan_curve_set_mode(fan, CURVE_MODE_LUT);
    } else if (strcmp(mode, "pid") == 0) {
        cJSON *kp = cJSON_GetObjectItem(root, "kp");
        cJSON *ki = cJSON_GetObjectItem(root, "ki");
        cJSON *kd = cJSON_GetObjectItem(root, "kd");
        cJSON *sp = cJSON_GetObjectItem(root, "setpoint_c");
        fan_curve_set_pid(fan, &(pid_params_t){
            .kp = kp ? (float)kp->valuedouble : 2.0f,
            .ki = ki ? (float)ki->valuedouble : 0.1f,
            .kd = kd ? (float)kd->valuedouble : 0.5f,
            .setpoint_c = sp ? (float)sp->valuedouble : 50.0f,
        });
        fan_curve_set_mode(fan, CURVE_MODE_PID);
    }
}

/* FW-20④: config/alert —— set 保存 NVS+应用；get 回读发布 */
static void save_alert_cfg_to_nvs(void)
{
    alert_thresholds_t th;
    alert_manager_get_thresholds(&th);
    char val[96];
    snprintf(val, sizeof(val), "%.1f,%.1f,%.2f,%.2f,%u,%u",
             th.temp_warn_c, th.temp_crit_c, th.v12_min, th.v12_max,
             th.stall_rpm, th.wifi_timeout_s);
    storage_write_config("alert_cfg", val);
}

static void load_alert_cfg_from_nvs(void)
{
    char val[96];
    if (storage_read_config("alert_cfg", val, sizeof(val)) != ESP_OK) return;
    alert_thresholds_t th;
    if (sscanf(val, "%f,%f,%f,%f,%hu,%hu",
               &th.temp_warn_c, &th.temp_crit_c, &th.v12_min, &th.v12_max,
               &th.stall_rpm, &th.wifi_timeout_s) == 6) {
        alert_manager_set_thresholds(&th);
        ESP_LOGI(TAG, "alert thresholds loaded from NVS");
    }
}

static void publish_alert_cfg(void)
{
    char topic[80];
    snprintf(topic, sizeof(topic), "%s/%s/config/alert",
             MQTT_TOPIC_PREFIX, s_device_id);
    alert_thresholds_t th;
    alert_manager_get_thresholds(&th);
    cJSON *root = cJSON_CreateObject();
    cJSON_AddNumberToObject(root, "timestamp", (double)time(NULL));
    cJSON_AddStringToObject(root, "device_id", s_device_id);
    cJSON *rules = cJSON_AddArrayToObject(root, "rules");
    cJSON *r;
    r = cJSON_CreateObject();
    cJSON_AddStringToObject(r, "type", "temperature_high");
    cJSON_AddNumberToObject(r, "warn_c",  th.temp_warn_c);
    cJSON_AddNumberToObject(r, "crit_c",  th.temp_crit_c);
    cJSON_AddBoolToObject(r, "enabled", true);
    cJSON_AddItemToArray(rules, r);
    r = cJSON_CreateObject();
    cJSON_AddStringToObject(r, "type", "fan_stall");
    cJSON_AddNumberToObject(r, "stall_rpm", th.stall_rpm);
    cJSON_AddBoolToObject(r, "enabled", true);
    cJSON_AddItemToArray(rules, r);
    r = cJSON_CreateObject();
    cJSON_AddStringToObject(r, "type", "voltage_abnormal");
    cJSON_AddNumberToObject(r, "12v_min", th.v12_min);
    cJSON_AddNumberToObject(r, "12v_max", th.v12_max);
    cJSON_AddBoolToObject(r, "enabled", true);
    cJSON_AddItemToArray(rules, r);
    r = cJSON_CreateObject();
    cJSON_AddStringToObject(r, "type", "wifi_disconnected");
    cJSON_AddNumberToObject(r, "timeout_s", th.wifi_timeout_s);
    cJSON_AddBoolToObject(r, "enabled", true);
    cJSON_AddItemToArray(rules, r);
    char *js = cJSON_PrintUnformatted(root);
    if (js) { mqtt_publish(topic, js, 1); free(js); }
    cJSON_Delete(root);
}

static void handle_config_alert(cJSON *root)
{
    /* get 回读：空对象或 {"get":true} */
    cJSON *get_j = cJSON_GetObjectItem(root, "get");
    if (get_j && cJSON_IsTrue(get_j)) {
        publish_alert_cfg();
        return;
    }

    cJSON *rules = cJSON_GetObjectItem(root, "rules");
    if (!cJSON_IsArray(rules)) {
        ESP_LOGW(TAG, "config/alert: no rules array, ignored");
        return;
    }

    alert_thresholds_t th;
    alert_manager_get_thresholds(&th);
    cJSON *r;
    cJSON_ArrayForEach(r, rules) {
        cJSON *type_j = cJSON_GetObjectItem(r, "type");
        if (!type_j || !type_j->valuestring) continue;
        alert_type_t t = alert_type_from_string(type_j->valuestring);
        cJSON *en_j = cJSON_GetObjectItem(r, "enabled");
        if (en_j && !cJSON_IsTrue(en_j)) continue;   /* 规则停用：保持默认 */
        cJSON *v;
        switch (t) {
            case ALERT_TYPE_TEMPERATURE:
                if ((v = cJSON_GetObjectItem(r, "threshold")) ||
                    (v = cJSON_GetObjectItem(r, "warn_c")))
                    th.temp_warn_c = (float)v->valuedouble;
                if ((v = cJSON_GetObjectItem(r, "crit_c")))
                    th.temp_crit_c = (float)v->valuedouble;
                break;
            case ALERT_TYPE_FAN_STALL:
                if ((v = cJSON_GetObjectItem(r, "threshold")))
                    th.stall_rpm = (uint16_t)v->valueint;
                break;
            case ALERT_TYPE_VOLTAGE:
                if ((v = cJSON_GetObjectItem(r, "12v_min")))
                    th.v12_min = (float)v->valuedouble;
                if ((v = cJSON_GetObjectItem(r, "12v_max")))
                    th.v12_max = (float)v->valuedouble;
                break;
            case ALERT_TYPE_WIFI:
                if ((v = cJSON_GetObjectItem(r, "threshold")))
                    th.wifi_timeout_s = (uint16_t)v->valueint;
                break;
            default:
                ESP_LOGW(TAG, "config/alert: unknown rule type '%s'",
                         type_j->valuestring);
                break;
        }
    }
    alert_manager_set_thresholds(&th);
    save_alert_cfg_to_nvs();
}

static void on_mqtt_command(const char *topic, int topic_len,
                             const char *data,  int data_len)
{
    /* Always use cJSON — never sscanf for JSON */
    char buf[1024];
    if (data_len <= 0 || data_len >= (int)sizeof(buf)) return;
    memcpy(buf, data, data_len);
    buf[data_len] = '\0';

    cJSON *root = cJSON_Parse(buf);
    if (!root) return;

    /* Route by topic suffix */
    char topic_str[128];
    int  len = (topic_len < 127) ? topic_len : 127;
    memcpy(topic_str, topic, len);
    topic_str[len] = '\0';

    /* FW-04: 防御性校验 —— topic 中的 device_id 与本机一致才执行 */
    if (strncmp(topic_str, MQTT_TOPIC_PREFIX "/", strlen(MQTT_TOPIC_PREFIX) + 1) == 0) {
        char topic_dev[16];
        const char *dev = topic_str + strlen(MQTT_TOPIC_PREFIX) + 1;
        const char *slash = strchr(dev, '/');
        size_t dev_len = slash ? (size_t)(slash - dev) : strlen(dev);
        if (dev_len >= sizeof(topic_dev)) dev_len = sizeof(topic_dev) - 1;
        memcpy(topic_dev, dev, dev_len);
        topic_dev[dev_len] = '\0';
        if (strcmp(topic_dev, s_device_id) != 0) {
            ESP_LOGW(TAG, "Command for other device '%s', ignored", topic_dev);
            cJSON_Delete(root);
            return;
        }
    }

    if (strstr(topic_str, "/command/fan")) {
        cJSON *idx_j  = cJSON_GetObjectItem(root, "fan_index");
        cJSON *duty_j = cJSON_GetObjectItem(root, "duty_pct");
        if (idx_j && duty_j) {
            /* FW-20⑤: 越界直接丢弃并记日志 */
            if (idx_j->valueint < 0 || idx_j->valueint >= FAN_PWM_COUNT ||
                duty_j->valueint < 0 || duty_j->valueint > 100) {
                ESP_LOGW(TAG, "command/fan: index/duty out of range, dropped");
            } else {
                fan_curve_set_mode((uint8_t)idx_j->valueint, CURVE_MODE_MANUAL);
                fan_pwm_set_duty((uint8_t)idx_j->valueint, (uint8_t)duty_j->valueint);
            }
        }
    } else if (strstr(topic_str, "/command/curve")) {          /* FW-20① */
        handle_curve_command(root);
    } else if (strstr(topic_str, "/command/ota")) {            /* ADJ-3 */
        cJSON *url_j = cJSON_GetObjectItem(root, "firmware_url");
        if (url_j && url_j->valuestring) {
            status_led_set_mode(LED_MODE_OTA);
            ota_handler_start(url_j->valuestring);
        }
    } else if (strstr(topic_str, "/command/reboot")) {
        ESP_LOGW(TAG, "Reboot command received");
        vTaskDelay(pdMS_TO_TICKS(500));
        esp_restart();
    } else if (strstr(topic_str, "/command/reset")) {          /* FW-20③ */
        cJSON *confirm_j = cJSON_GetObjectItem(root, "confirm");
        if (confirm_j && cJSON_IsTrue(confirm_j)) {
            ESP_LOGW(TAG, "Factory reset confirmed — erasing + rebooting");
            wifi_manager_factory_reset();     /* FW-28: 三 namespace 统一清理 */
            vTaskDelay(pdMS_TO_TICKS(500));
            esp_restart();
        } else {
            ESP_LOGW(TAG, "reset without confirm:true — ignored");
        }
    } else if (strstr(topic_str, "/config/alert")) {           /* FW-20④ */
        handle_config_alert(root);
    }

    cJSON_Delete(root);
}

/* ---- USB console commands（FW-22: help/status/reboot/ota/fan/wifi/mqtt） ---- */
static char *cmd_status(const char *args)
{
    (void)args;
    cJSON *root = cJSON_CreateObject();
    cJSON_AddBoolToObject  (root, "ok",           true);
    cJSON_AddBoolToObject  (root, "wifi",         s_wifi_connected);
    cJSON_AddBoolToObject  (root, "mqtt",         mqtt_client_is_connected());
    cJSON_AddNumberToObject(root, "uptime_s",     (double)(esp_timer_get_time() / 1000000LL));
    cJSON_AddNumberToObject(root, "free_heap",    (double)esp_get_free_heap_size());
    cJSON_AddNumberToObject(root, "alert_level",  alert_manager_get_severity());
    char *js = cJSON_PrintUnformatted(root);
    cJSON_Delete(root);
    return js;
}

static char *cmd_ota(const char *args)
{
    if (!args || args[0] == '\0') {
        return strdup("{\"ok\":false,\"error\":\"usage: ota <url>\"}");
    }
    status_led_set_mode(LED_MODE_OTA);
    ota_handler_start(args);
    return strdup("{\"ok\":true,\"message\":\"OTA started\"}");
}

/* FW-22: fan <0-7> <duty 0-100>（验收流程依赖） */
static char *cmd_fan(const char *args)
{
    int fan = -1, duty = -1;
    if (!args || sscanf(args, "%d %d", &fan, &duty) != 2) {
        return strdup("{\"ok\":false,\"error\":\"usage: fan <0-7> <duty 0-100>\"}");
    }
    if (fan < 0 || fan >= FAN_PWM_COUNT || duty < 0 || duty > 100) {
        return strdup("{\"ok\":false,\"error\":\"fan index 0-7, duty 0-100\"}");
    }
    fan_curve_set_mode((uint8_t)fan, CURVE_MODE_MANUAL);
    fan_pwm_set_duty((uint8_t)fan, (uint8_t)duty);
    char resp[64];
    snprintf(resp, sizeof(resp), "{\"ok\":true,\"fan\":%d,\"duty\":%d}", fan, duty);
    return strdup(resp);
}
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
void app_main(void)
{
    ESP_LOGI(TAG, "==============================================");
    ESP_LOGI(TAG, "  Smart Fan Controller %s", FW_VERSION);
    ESP_LOGI(TAG, "  Platform: ESP32-S3-N16R8 (8 fans)");
    ESP_LOGI(TAG, "==============================================");

    /* Derive device ID from MAC */
    uint8_t mac[6];
    esp_base_mac_addr_get(mac);
    snprintf(s_device_id, sizeof(s_device_id), "esp32-%02x%02x%02x", mac[3], mac[4], mac[5]);
    ESP_LOGI(TAG, "Device ID: %s", s_device_id);

    /* 0. FW-13: LEDC duty=0 最先配置（上电安全态，缩短缓冲输入悬空窗口；
     *    与硬件下拉 H-17 双保险） */
    ESP_ERROR_CHECK(fan_pwm_init());
    ESP_LOGI(TAG, "[0/7] Fan PWM safe-state OK (8ch duty=0)");

    /* 1. NVS */
    esp_err_t ret = nvs_flash_init();
    if (ret == ESP_ERR_NVS_NO_FREE_PAGES || ret == ESP_ERR_NVS_NEW_VERSION_FOUND) {
        ESP_ERROR_CHECK(nvs_flash_erase());
        ret = nvs_flash_init();
    }
    ESP_ERROR_CHECK(ret);
    ESP_LOGI(TAG, "[1/7] NVS OK");

    /* 2. Flash storage */
    ESP_ERROR_CHECK(flash_storage_init());
    ESP_LOGI(TAG, "[2/7] Flash storage OK");

    /* 3. Fan drivers: Tach + 曲线（含 NVS 加载，FW-20） */
    ESP_ERROR_CHECK(fan_tach_init());
    fan_tach_on_stall(on_fan_stall);
    ESP_ERROR_CHECK(fan_curve_init());
    ESP_LOGI(TAG, "[3/7] Tach + curve OK");

    /* 4. Alert + LED */
    ESP_ERROR_CHECK(status_led_init());
    status_led_set_mode(LED_MODE_WIFI_DISCONNECTED);
    ESP_ERROR_CHECK(alert_manager_init(on_alert, on_alert_clear));
    load_alert_cfg_from_nvs();      /* FW-20④: config/alert 持久化恢复 */
    ESP_LOGI(TAG, "[4/7] Alert + LED OK");

    /* 5. Sensors */
    ESP_ERROR_CHECK(power_monitor_init());
    ESP_ERROR_CHECK(bme280_init());
    ESP_ERROR_CHECK(ds18b20_init());
    ESP_LOGI(TAG, "[5/7] Sensors OK");

    /* 6. OTA + USB console */
    ESP_ERROR_CHECK(ota_handler_init());
    ota_handler_confirm_boot(); /* OTA Phase 1: boot confirmed */
    ESP_ERROR_CHECK(usb_console_init());
    console_register_command("status", cmd_status);
    console_register_command("ota",    cmd_ota);
    console_register_command("fan",    cmd_fan);     /* FW-22 */
    console_register_command("wifi",    cmd_wifi);   /* FW-22 */
    console_register_command("mqtt",    cmd_mqtt);   /* FW-22 */
    ESP_LOGI(TAG, "[6/7] OTA + USB console OK");

    /* 7. WiFi + MQTT 最后（FW-12: 失败不 abort——本地模式运行，后台重试） */
    esp_err_t err = wifi_manager_init(on_wifi_connected, on_wifi_disconnected);
    if (err != ESP_OK) {
        ESP_LOGE(TAG, "WiFi init failed (%s) — running in local mode",
                 esp_err_to_name(err));
    } else {
        err = wifi_manager_start();
        if (err != ESP_OK) {
            ESP_LOGE(TAG, "WiFi start failed (%s) — running in local mode",
                     esp_err_to_name(err));
        }
    }

    err = mqtt_client_init();
    if (err != ESP_OK) {
        ESP_LOGE(TAG, "MQTT init failed (%s)", esp_err_to_name(err));
    } else {
        /* FW-04: 具体设备订阅（不用 + 通配）；FW-03: 连接建立后才真正下发 */
        char sub_topic[80];
        snprintf(sub_topic, sizeof(sub_topic), "%s/%s/command/#",
                 MQTT_TOPIC_PREFIX, s_device_id);
        mqtt_subscribe(sub_topic, on_mqtt_command);
        snprintf(sub_topic, sizeof(sub_topic), "%s/%s/config/#",
                 MQTT_TOPIC_PREFIX, s_device_id);
        mqtt_subscribe(sub_topic, on_mqtt_command);
        mqtt_client_set_connected_cb(on_mqtt_connected);   /* FW-08 */
    }
    ESP_LOGI(TAG, "[7/7] WiFi + MQTT init OK (local mode if not connected)");

    /* Spawn FreeRTOS tasks */
    xTaskCreatePinnedToCore(sensor_task,       "sensor",   4096, NULL, 3, NULL, 1);
    xTaskCreatePinnedToCore(fan_control_task,  "fan_ctrl", 4096, NULL, 3, NULL, 1);
    xTaskCreatePinnedToCore(tach_monitor_task, "tach_mon", 3072, NULL, 3, NULL, 1);
    xTaskCreatePinnedToCore(alert_task,        "alert",    3072, NULL, 2, NULL, 1);
    /* mqtt_task and wifi_task are driven by esp_mqtt and esp_wifi internally */

    ESP_LOGI(TAG, "All systems operational — %s ready", s_device_id);
}

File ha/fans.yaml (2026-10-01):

# ha/fans.yaml — 风扇控制实体 (HA MQTT fan 组件, 8 路)
# HA-01: __DEVICE_ID__ 为显眼占位符，安装时必须替换（见 ha/README.md）
# HA-02: 8 路风扇（v1.2 硬件决策 D2）
# HA-05: availability 联动设备 LWT status topic
mqtt:
  fan:
    - name: "Fan 0"
      unique_id: "fan_ctrl_fan0"
      command_topic: "fan-controller/__DEVICE_ID__/command/fan"
      payload_on: >
        {"fan_index":0,"mode":"manual","duty_pct":100,"timestamp":0}
      payload_off: >
        {"fan_index":0,"mode":"manual","duty_pct":0,"timestamp":0}
      percentage_command_topic: "fan-controller/__DEVICE_ID__/command/fan"
      percentage_command_template: >
        {"fan_index":0,"mode":"manual","duty_pct":{{ value }},"timestamp":0}
      percentage_state_topic: "fan-controller/__DEVICE_ID__/fan/0/state"
      percentage_value_template: "{{ value_json.pwm_duty_pct }}"
      speed_range_min: 0
      speed_range_max: 100
      availability_topic: "fan-controller/__DEVICE_ID__/status"
      availability_template: "{{ 'online' if value_json.status == 'online' else 'offline' }}"
      device:
        identifiers: ["fan_ctrl___DEVICE_ID__"]
        name: "Smart Fan Controller"

    - name: "Fan 1"
      unique_id: "fan_ctrl_fan1"
      command_topic: "fan-controller/__DEVICE_ID__/command/fan"
      payload_on: >
        {"fan_index":1,"mode":"manual","duty_pct":100,"timestamp":0}
      payload_off: >
        {"fan_index":1,"mode":"manual","duty_pct":0,"timestamp":0}
      percentage_command_topic: "fan-controller/__DEVICE_ID__/command/fan"
      percentage_command_template: >
        {"fan_index":1,"mode":"manual","duty_pct":{{ value }},"timestamp":0}
      percentage_state_topic: "fan-controller/__DEVICE_ID__/fan/1/state"
      percentage_value_template: "{{ value_json.pwm_duty_pct }}"
      speed_range_min: 0
      speed_range_max: 100
      availability_topic: "fan-controller/__DEVICE_ID__/status"
      availability_template: "{{ 'online' if value_json.status == 'online' else 'offline' }}"
      device:
        identifiers: ["fan_ctrl___DEVICE_ID__"]

    - name: "Fan 2"
      unique_id: "fan_ctrl_fan2"
      command_topic: "fan-controller/__DEVICE_ID__/command/fan"
      payload_on: >
        {"fan_index":2,"mode":"manual","duty_pct":100,"timestamp":0}
      payload_off: >
        {"fan_index":2,"mode":"manual","duty_pct":0,"timestamp":0}
      percentage_command_topic: "fan-controller/__DEVICE_ID__/command/fan"
      percentage_command_template: >
        {"fan_index":2,"mode":"manual","duty_pct":{{ value }},"timestamp":0}
      percentage_state_topic: "fan-controller/__DEVICE_ID__/fan/2/state"
      percentage_value_template: "{{ value_json.pwm_duty_pct }}"
      speed_range_min: 0
      speed_range_max: 100
      availability_topic: "fan-controller/__DEVICE_ID__/status"
      availability_template: "{{ 'online' if value_json.status == 'online' else 'offline' }}"
      device:
        identifiers: ["fan_ctrl___DEVICE_ID__"]

    - name: "Fan 3"
      unique_id: "fan_ctrl_fan3"
      command_topic: "fan-controller/__DEVICE_ID__/command/fan"
      payload_on: >
        {"fan_index":3,"mode":"manual","duty_pct":100,"timestamp":0}
      payload_off: >
        {"fan_index":3,"mode":"manual","duty_pct":0,"timestamp":0}
      percentage_command_topic: "fan-controller/__DEVICE_ID__/command/fan"
      percentage_command_template: >
        {"fan_index":3,"mode":"manual","duty_pct":{{ value }},"timestamp":0}
      percentage_state_topic: "fan-controller/__DEVICE_ID__/fan/3/state"
      percentage_value_template: "{{ value_json.pwm_duty_pct }}"
      speed_range_min: 0
      speed_range_max: 100
      availability_topic: "fan-controller/__DEVICE_ID__/status"
      availability_template: "{{ 'online' if value_json.status == 'online' else 'offline' }}"
      device:
        identifiers: ["fan_ctrl___DEVICE_ID__"]

    - name: "Fan 4"
      unique_id: "fan_ctrl_fan4"
      command_topic: "fan-controller/__DEVICE_ID__/command/fan"
      payload_on: >
        {"fan_index":4,"mode":"manual","duty_pct":100,"timestamp":0}
      payload_off: >
        {"fan_index":4,"mode":"manual","duty_pct":0,"timestamp":0}
      percentage_command_topic: "fan-controller/__DEVICE_ID__/command/fan"
      percentage_command_template: >
        {"fan_index":4,"mode":"manual","duty_pct":{{ value }},"timestamp":0}
      percentage_state_topic: "fan-controller/__DEVICE_ID__/fan/4/state"
      percentage_value_template: "{{ value_json.pwm_duty_pct }}"
      speed_range_min: 0
      speed_range_max: 100
      availability_topic: "fan-controller/__DEVICE_ID__/status"
      availability_template: "{{ 'online' if value_json.status == 'online' else 'offline' }}"
      device:
        identifiers: ["fan_ctrl___DEVICE_ID__"]
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

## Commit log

2026-07-30 feat: Smart Fan Controller — ESP32-S3 server fan management system
    Complete implementation:
    - Firmware: 13 ESP-IDF components (fan_pwm/tach, bme280, ds18b20, wifi, mqtt,
    ota, usb_console, flash_storage, fan_curve, alert_manager, power_monitor,
    status_led) + full Unity test suite
    - Go Agent: GPU (nvidia-smi) + system (/proc) monitoring, MQTT relay, USB-CDC
    - Web: React dashboard + Express API + WebSocket + Recharts charts
    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
    [BOM.csv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]
2026-07-30 docs: add 🌀 emoji favicon to GitHub Pages
2026-08-21 fix: remove semicolon comments from KiCad PCB file
    KiCad S-expression format does not support semicolon comments.
    Removed 22 comment lines causing parse error at line 63.
    [smart-fan-controller.kicad_pcb]
2026-08-21 fix: remove v7 keepout zone for KiCad v10 compatibility
    - KiCad v7 format (version 20221018) incompatible with v10
    - Remove zone definition to allow file to open in v10
    - Keepout area marked with silkscreen text for manual re-creation
    - v10 will auto-upgrade file format on first save
    [smart-fan-controller.kicad_pcb]
2026-08-21 feat: add KiCad project and schematic files
    - Create .kicad_pro project file with v10 settings
    - Add simplified .kicad_sch with ESP32-S3 core module
    - Enable proper PCB editing with netlist support
    - Configure design rules: 0.2mm clearance, power class 1.0mm tracks
    - Add placeholder schematic noting required circuits
    [smart-fan-controller.kicad_sch]
2026-08-23 docs: add complete hardware design guide for LCEDA v1.1
    - Main board: 6-channel independent fan control (upgraded from 4)
    - Expansion board: 12-channel unified control design
    - Full BOM with LCSC part numbers and Taobao keywords
    - Schematic drawing guide with 7 modules breakdown
    - PCB layout constraints for JLCPCB manufacturing
    - Schematic review checklist (12 sections, 100+ items)
    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
2026-08-23 docs: correct hardware design guide - remove custom expansion board
    Changes:
    - Clarified that expansion board is a pre-purchased product (not DIY)
    - Removed custom expansion board BOM and schematic design
    - Removed J11 connector (PH2.0 3P) for expansion board
    - Removed GPIO13 dedicated expansion output
    - Simplified to pure 6-channel independent fan control
    - Fan6 (J8) can connect to external 12-fan expansion board via standard 4Pin
    - Total fans: 5 independent + 12 unified (via expansion) = 17 fans
    - Updated GPIO allocation table and module descriptions
    [task-10-ledc-config.txt]
2026-10-01 chore: untrack AI process artifacts (.omo/.sisyphus) per DOC-05
    - .gitignore: add .omo/, .sisyphus/, .claude/ and *.bak, *.v7backup (H-15)
    - remove 76 AI evidence/plan/draft files from git tracking (kept on disk)
    [task-10-ledc-config.txt]
2026-10-01 chore: archive legacy KiCad project and v1.1 docs under hardware/legacy (decision D6)
    - move KiCad pro/sch/pcb, text placeholder schematics, gerber/ to hardware/legacy/
    - move v1.1 design guide and BOM docs to hardware/legacy/docs/
    - drop smart-fan-controller.kicad_pcb.v7backup from tracking (kept on disk)
    [SmartFan_B_Cu.gbr, SmartFan_B_Mask.gbr, SmartFan_B_Silkscreen.gbr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]
2026-10-01 docs: add v1.2 module review/remediation reports and sync guides
    - new: module-review-plan/report, module-remediation-plan-v1.2, module-recheck, changelog-modules-v1.2
    - deploy.md / hardware-assembly.md / protocol.md: v1.2 pin map and 8-fan alignment (DOC-03/04)
    - README.md: 8-channel scope, build commands corrected (no web npm test, firmware tests descope DOC-06)
    - docs/index.html: GitHub Pages sync
2026-10-01 fix(firmware): v1.2 remediation — pin sync, MQTT, OTA, alerts, NVS
    - H-03 pin map v1.2: PWM GPIO5-12, tach GPIO13/14/15/21/38/39/40/41 (PCNT 4u x2ch),
    ADC GPIO1/2/4 (divider 6.0/5.7/5.7), LED GPIO45, button GPIO47, console via USB-Serial-JTAG
    - FW-01/02 build fixes (status_led esp_err_t, main REQUIRES all 13 components) — idf.py build pass
    - FW-03/04 subscribe-on-connect with cached topics + device_id scoped to <id>/command/#
    - FW-05 proper FreeRTOS timer callback for delayed MQTT start
    - FW-06 NVS offline queue on dedicated keys (no broker_url namespace wipe)
    - alert stop-rotor logic fixed (rpm==0 alerts), timestamp = Unix seconds (MA-12)
    - add usb_console idf_component.yml + dependen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
    [partitions.csv]
2026-10-01 fix(agent): repair build chain and complete wiring (AG-01/02/08)
    - drop unused import, go.sum in repo, go.bug.st/serial v1.8.0 (removes dead creack deps)
    - main.go full wiring: config -> MQTT -> collectors -> optional --relay USB bridge
    - add smart-fan-agent.service (replaces deleted agent.service)
    - GOOS=linux build + vet pass
2026-10-01 fix(web): restore build chain and apply v1.2 fixes (MC-01/02)
    - frontend: tsconfig + tsconfig.node + vite.config + index.html + main.tsx (tsc && vite build pass)
    - backend: tsconfig strict + package-lock (dist/server.js builds)
    - 8-fan scope and protocol field alignment across pages/components
2026-10-01 fix(ha): 8 fan entities, device_id scoping, availability (MD-01/02)
    - fans.yaml expanded to 8 fan entities with command topics under <device_id>/command/
    - __DEVICE_ID__ placeholder consistent across sensors/fans/alerts (no esp32-placeholder)
    - all entities availability-wired to LWT status topic
    [fans.yaml]
2026-10-01 docs(hardware): v1.2 design guide, remediation plan, EDA reference assets
    - new: hardware-design-guide-v1.2.md, remediation-plan-v1.2.md, changelog-v1.2.md
    - schematic-review-checklist v1.2 (GPIO table, PWM pull-downs, USBLC6 VCC, F1, NC pins)
    - kicad-reference/: v1.2 reference schematic project + PDF (non-authoritative)
    - lceda-ref/: EasyEDA Pro API reference scripts + README (D6: user's LCEDA project is the single source)
    [smart-fan-controller-v1.2.kicad_sch]
2026-10-01 docs: archive Linux server deployment verification report (2026-10-02)
    Track A verification on Ubuntu 24.04 (192.168.3.131): smoke PASS 25/FAIL 0,
    end-to-end MQTT->backend->WS->frontend->agent confirmed. Findings: 1xP0
    (Group=nobody), 1xP1 (Go toolchain), 11x deploy.md revisions, 3x doc mismatches.
2026-10-01 fix(agent): drop Group=nobody from systemd unit (breaks Debian/Ubuntu)
    Group 'nobody' does not exist on Debian/Ubuntu (gid 65534 is 'nogroup'), so the
    service failed with status=216/GROUP and never started. Omitting Group= makes
    systemd fall back to the primary group of User=nobody on every distro.
    Found in Track A deployment verification (docs/verification/), F1/P0.
2026-10-01 feat(test): add protocol simulator
    新增 test/simulator/：无 ESP32 真机时用 Node.js 模拟设备 esp32-sim0001，
    让 Web / HA / 冒烟链路可做全链路验证（协议真源 docs/protocol.md v1.0.1）。
    - 周期上报 status(online, QoS1+retain)/bme280/ds18b20/voltage/internal_temp/
    8 路 fan state 与告警事件；timestamp 统一 Unix 秒（FW-15）；LWT 发 retained offline
    - 响应 command/# 与 config/#：fan（MANUAL + duty→rpm 随动）、curve（AUTO/LUT/PID、
    temp_c 严格递增校验）、reboot（offline→重连回执）、reset（confirm 门控）、
    ota（downloading→verifying→success→重启换版本）、config/alert get/set 回读
    - 数值缓慢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
2026-10-01 docs: archive simulator verification report (Track B) and wire simulator into README
    - docs/verification/simulator-verification-20261002.md: contract selftest PASS 43/0,
    smoke regression PASS 25/0, web full-chain evidence (4 screenshots + 2 logs)
    - README: simulator usage section, exec-bit-free smoke command, 8-static-assertion note
2026-10-01 feat(web,backend): console redesign — i18n, glacier design system, fan UX, real history
    frontend:
    - react-i18next zh-CN/en-US dual language, zero hardcoded copy, sidebar switcher
    - Tailwind CSS 4 + CSS-variable dual theme (dark default), glass cards, HUD accents,
    chart tokens; vite manualChunks (main 600kB -> 139kB)
    - single WS provider app-wide (was 5 per-page connections + duplicated constants)
    - Dashboard: hero device card, SVG temp rings, tolerance-window voltage bars, fan array
    - Fans v2: live-debounced slider (150ms), optimistic mode with anti-flap, duty presets,
    AUTO hit explanation (source temp -> LUT segment -> target), ring gauges
    - Curve editor: per-fan drawer, draggable SVG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

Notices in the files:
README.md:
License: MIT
